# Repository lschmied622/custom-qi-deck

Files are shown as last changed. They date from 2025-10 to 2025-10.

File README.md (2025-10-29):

# README — Crazyflie „Custom-Qi-Deck“ (DE/EN)

> **Kurzbeschreibung.** Dieses Repository bündelt alle Artefakte der Bachelorarbeit zur Entwicklung eines *Custom-Qi-Decks* für die Crazyflie-Plattform, inklusive Elektronik (PCB), Mechanik (3D-Druck), Firmware und Skripten. Das Deck nutzt die **1-Wire-Deck-Identifikation** der Crazyflie 2.x, sodass beim Booten automatisch der passende Treiber geladen wird. Ohne beschriebene *Deck-EEPROM/One-Wire-Memory* stoppt die Drohne den Bootvorgang, bei nicht korrekt beschriebenem Speicher lädt die Drohne den Treiber nicht, weshalb die nachfolgenden Schritte zur EEPROM-Programmierung obligatorisch sind, um eine korrekte Funktionalität des Gesamtsystems zu gewährleisten. ([Bitcraze][1])

---

## 🇩🇪 Deutsch

### 1. Projektüberblick und Repository-Struktur

Die Ordnerstruktur ist bewusst so gewählt, dass Einsteigerinnen und Einsteiger schnell handlungsfähig werden:

```
bachelor-thesis/
├── README.md
├── LICENSE
├── docs/
│   ├── thesis/                # Thesis-Quellen (LaTeX/Word)
│   ├── figures/               # Abbildungen
│   └── presentations/         # Foliensätze
├── software/
│   ├── stm32-firmware/        # Crazyflie-STM32-Firmware
│   ├── nrf-firmware/          # NRF51-Firmware
│   ├── python-scripts/        # Tools, Analyse, Kontrolle
│   └── shared-libraries/      # Gemeinsame Bibliotheken
├── hardware/
│   ├── kicad-project/         # KiCad (.sch, .kicad_pcb, ...)
│   ├── fabrication-files/     # Gerber, BoM, Pick&Place
│   └── images/                # Fotos PCB/Bestückung
├── mechanics/
│   ├── cad-models/            # STEP/STL/Fusion
│   ├── animations/            # Render/Simulation
│   ├── images/                # Renders/Exploded Views
│   └── videos/                # Demo-/Montagevideos
└── experiments/
    ├── flight-tests/
    ├── sensor-logs/
    └── analysis/
```

---

### 2. Voraussetzungen (kurz)

* **Hardware:** Crazyflie 2.x + Radio (Crazyradio PA), Flow-Deck & Multi-ranger (optional, je nach Versuch), *Custom-Qi-Deck* (dieses Projekt).
* **Software:** Python 3.10+, `cflib` (Crazyflie Python Library), Crazyflie Client (optional für Konsole/Log-Ansicht).
* **Werkzeuge:** KiCad (für Anpassungen), gängige PCB-Bestückungsausrüstung.

---

### 3. PCB bestellen und bestücken

**3.1 Fertigungsdateien verwenden.** Im Ordner `hardware/fabrication-files/` liegen **Gerber-Daten**, **BoM** (Stückliste) und **Pick-and-Place**-Dateien. Diese sind bei üblichen PCB-Fertigern direkt hochladbar.

> *Hinweis:* Die Crazyflie-Decks werden über die 2×5-Stiftleisten und einen **1-Wire-Memory-Chip** identifiziert, der auf dem PCB bestückt sein muss (siehe Abschnitt 4). ([Bitcraze][1])

**3.2 BoM (Stückliste).** Die BoM enthält **alle** Bauteile zur vollständigen Bestückung, inkl. des 1-Wire-Memorys. Prüfen Sie vor Bestellung die Gehäuseformen und Lötpads.

**3.3 Kurze Montageanleitung.** (Angelehnt an die Thesis-Montagekapitel)

1. **Vorbereitung:** Leiterplatte reinigen; Bauteile gemäß BoM bereitstellen.
2. **Kleinteile (SMD) löten:** Zuerst passiv, dann ICs; besonders sauber: Qi-Empfänger, Gleichrichter/Power-Path, **1-Wire-Memory**.
3. **Verbinder setzen:** Headerleisten (2×10) exakt rechtwinklig.
4. **Mechanik prüfen:** Deckform und ggf. 3D-gedruckte Führung/„Ladetrichter“ aus `mechanics/cad-models/` kontrollieren und anpassen.
5. **Sichtprüfung & Reinigung:** Kurzschlussprüfung, Flussmittelreste entfernen.

> *Die Crazyflie liest am Start alle 1-Wire-Memories der Decks und initialisiert deren Treiber. Ein leeres/fehlerhaftes Deck-Memory kann das Starten verhindern oder die Funktionalität der anderen Decks, insbesondere dem Flowdeck, beeinflussen
> .* ([Bitcraze][1])

*Vorschau-Bilder:*

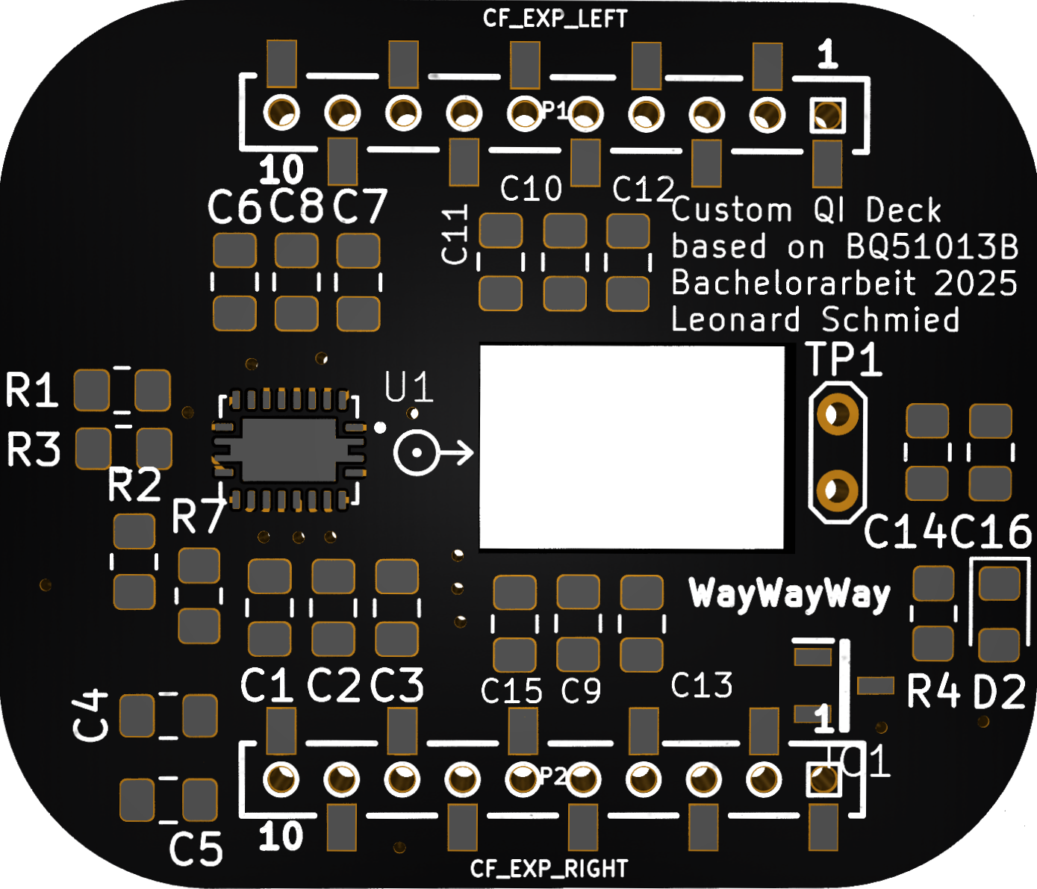
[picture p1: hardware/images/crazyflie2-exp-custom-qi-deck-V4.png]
Custom-Qi-Deck-frontsilk
 
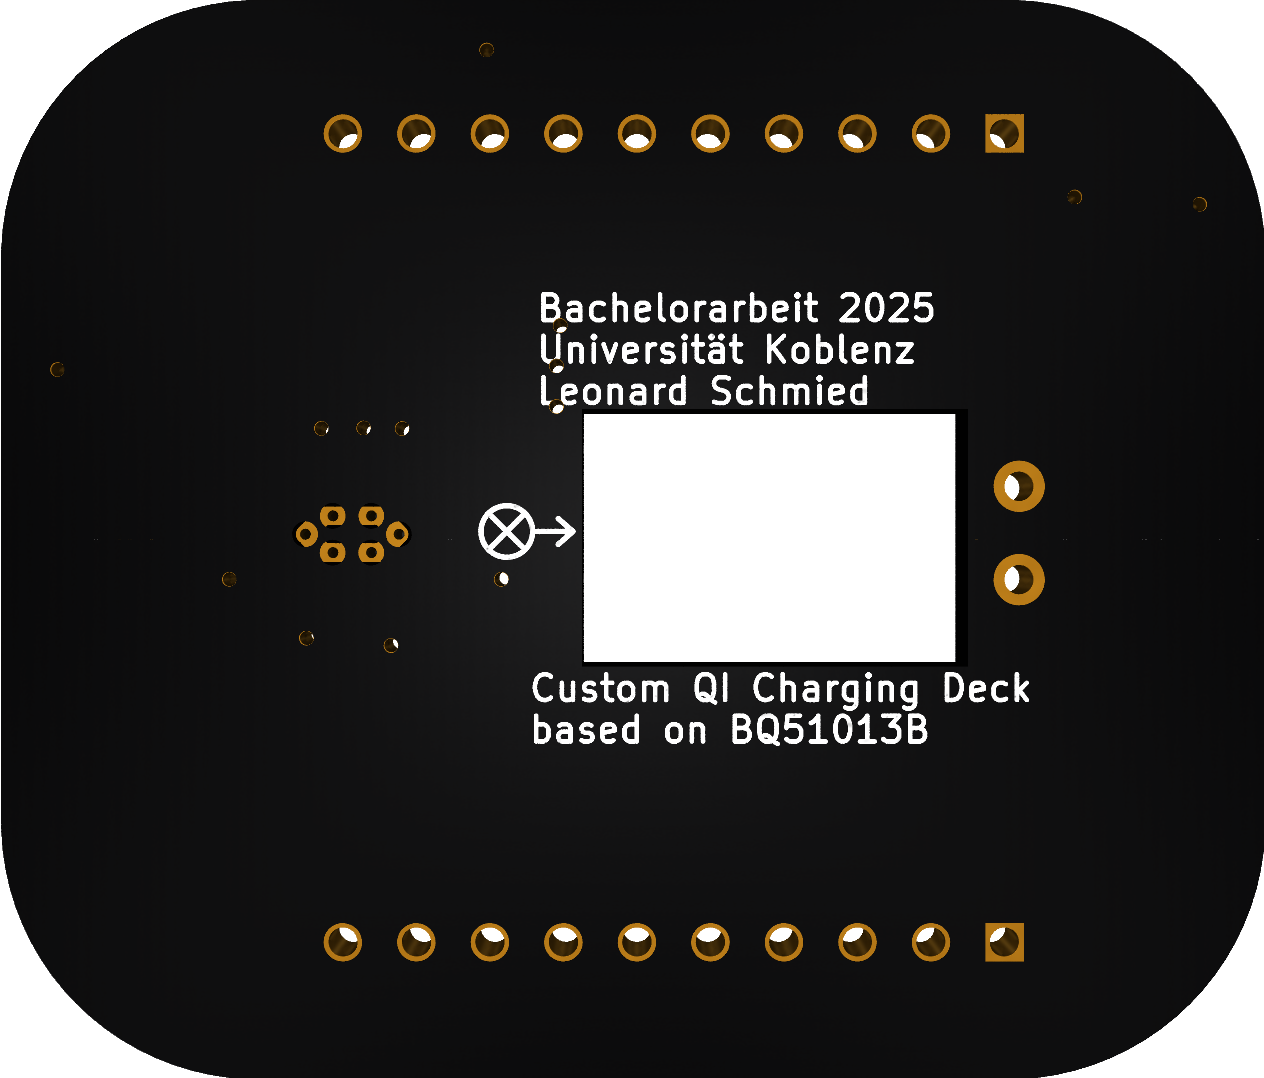
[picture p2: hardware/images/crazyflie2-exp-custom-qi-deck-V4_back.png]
Custom-Qi-Deck-backsilk


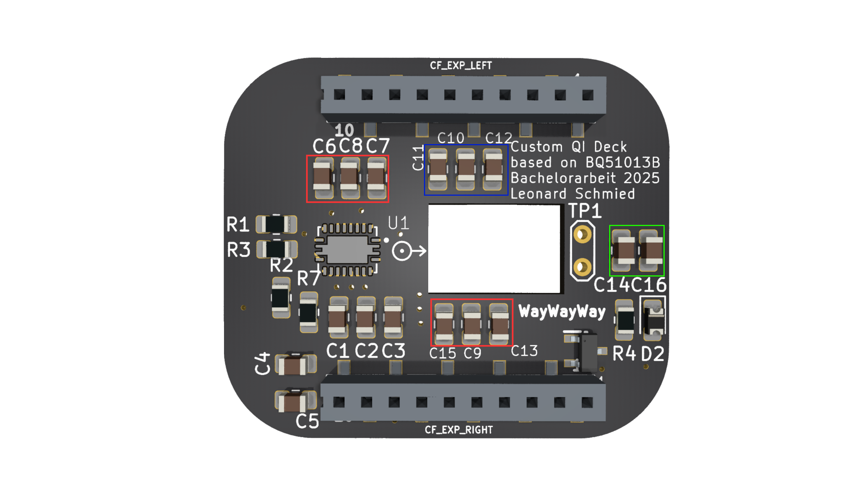
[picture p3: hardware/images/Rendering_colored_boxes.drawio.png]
Bestücktes PCB

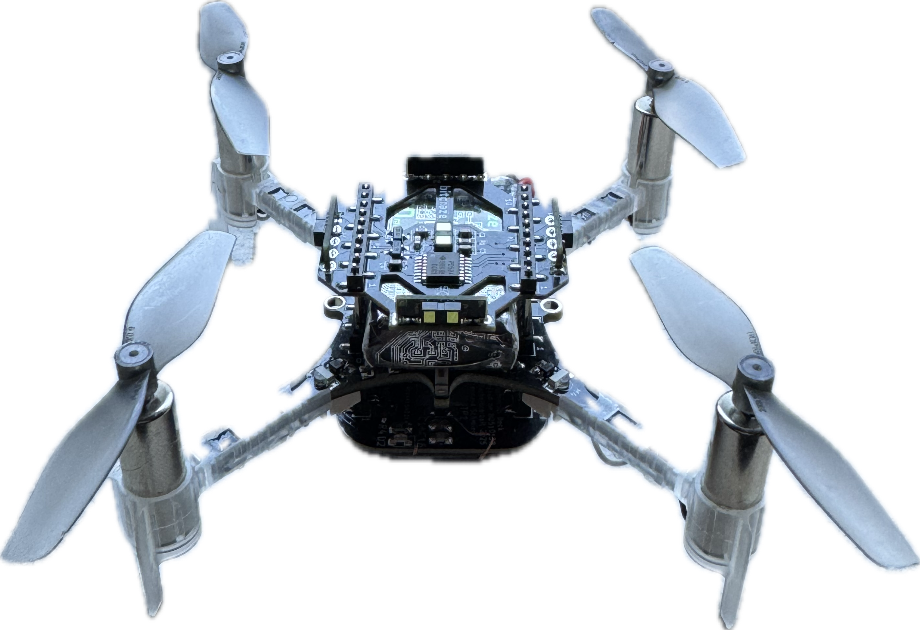
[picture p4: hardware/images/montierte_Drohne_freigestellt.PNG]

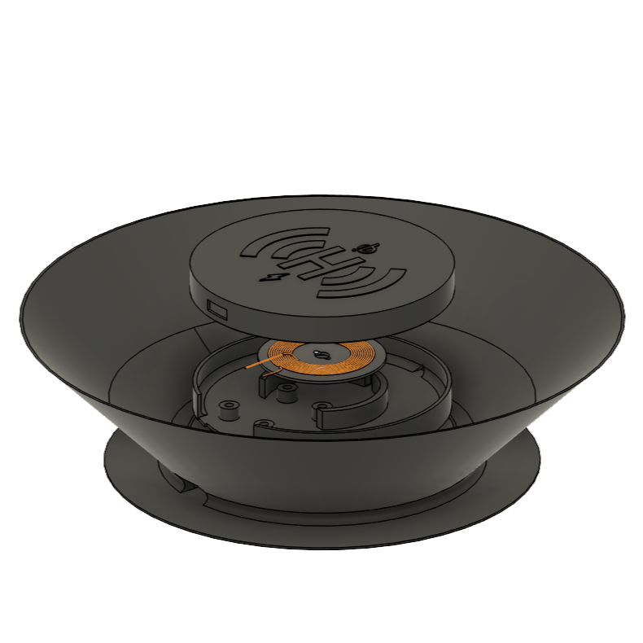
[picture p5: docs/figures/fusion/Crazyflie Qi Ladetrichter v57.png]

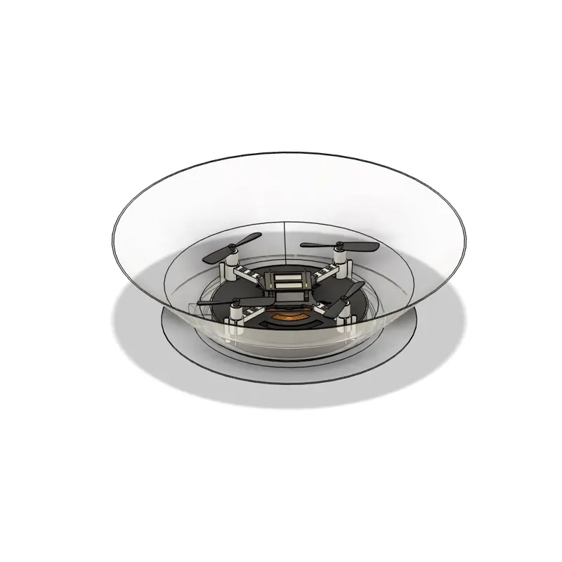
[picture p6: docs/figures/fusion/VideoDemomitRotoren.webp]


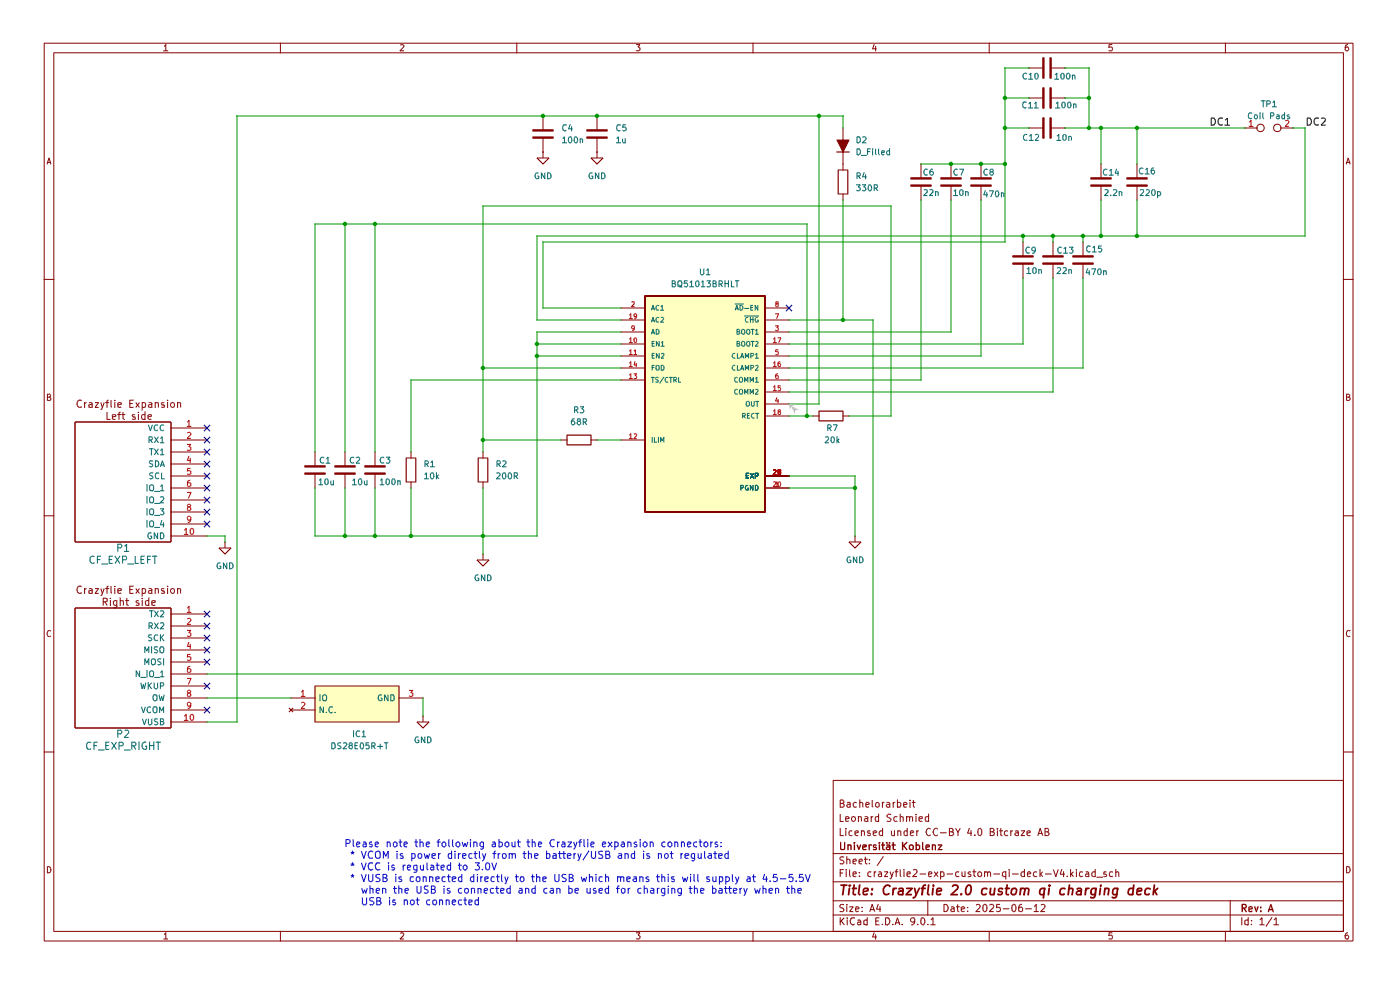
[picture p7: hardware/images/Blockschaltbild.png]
Qi-Schaltung (Prinzipskizze)


---

### 4. **Obligatorisch:** EEPROM/One-Wire-Memory programmieren

**Ziel.** Das Deck-EEPROM enthält Identitätsdaten (Vendor/Produkt/Name/Version), die der Crazyflie-Firmware erlauben, **Kompatibilität zu prüfen** und den **Treiber automatisch zu laden** (*Deck Enumeration*). ([Bitcraze][1])

**Werkzeuge.** Bitcraze stellt CRTP-basierte *Memory-Access*-Funktionen sowie Beispielskripte zum **Lesen/Schreiben des 1-Wire-Speichers** bereit (z. B. `read-ow.py`/`write-ow.py` in der Crazyflie-Python-Bibliothek). ([Bitcraze][2])

**Vorgehen (empfohlen):**

1. Crazyflie einschalten; per Radio verbinden.
2. Skript `write-ow.py` (oder eigenes Tool) verwenden, um das Deck-Memory zu beschreiben.
3. Reboot; Konsole prüfen (siehe **Validierung**).

**⚠️ WICHTIG:** Ohne korrekt geschriebenes EEPROM kann die Bootsequenz abbrechen bzw. der Treiber wird nicht geladen. ([Bitcraze][1])

**Platzhalter für Python-Code (anpassbar):**

```python
# replace method with this data:
    def _connected(self, link_uri):
        """ This callback is called form the Crazyflie API when a Crazyflie
        has been connected and the TOCs have been downloaded."""
        print('Connected to %s' % link_uri)

        mems = self._cf.mem.get_mems(MemoryElement.TYPE_1W)
        print('Found {} 1-wire memories'.format(len(mems)))
        if len(mems) > 0:
            print('Writing test configuration to'
                  ' memory {}'.format(mems[0].id))

            deck_name = 'custom_qi'

            # Setting VID:PID to 00:00 will make the Crazyflie match driver to the board name
            mems[0].vid = 0x00 #0xBC
            mems[0].pid = 0x00 #0x0F
            mems[0].pins = 0x0C #0x0C
            mems[0].name = deck_name
            mems[0].valid = True

            board_name_id = OWElement.element_mapping[1]
            board_rev_id = OWElement.element_mapping[2]

            mems[0].elements[board_name_id] = deck_name
            mems[0].elements[board_rev_id] = 'A'

            mems[0].write_data(self._data_written)
# TODO: Mit cflib examples/memory/write-ow.py an Deck schreiben.
```

> *Hinweis:* Details zum **Deck-Memory-Format** und zur **Memory-API** finden sich in der offiziellen Dokumentation. Stimmen Sie Felder und Prüfsummen mit dem verwendeten Tooling ab. ([Bitcraze][3])

---

### 5. Validierung (Konsole/Boot-Logs)

Nach dem Neustart sollte die Crazyflie in der **Konsole** (Crazyflie-Client) ausgeben, dass ein Deck-Memory gefunden wurde und der passende Treiber geladen ist. Suchen Sie nach Mustern wie:

```
...
DECK_CORE: 3 deck(s) found
DECK_CORE: Calling INIT on driver custom_qi for deck 0
[CUSTOM_QI] driver initialized
DECK_CORE: Calling INIT on driver bcMultiranger for deck 1
[CUSTOM_QI] task started
DECK_CORE: Calling INIT on driver bcFlow2 for deck 2
...
DECK_CORE: Deck 0 test [OK].
...
DECK_CORE: Deck 1 test [OK].
DECK_CORE: Deck 2 test [OK].
SYS: Self test passed!
STAB: Wait for sensor calibration...
SYS: Free heap: 12432 bytes
STAB: Starting stabilizer loop
```

> *Je nach Firmwareversion variieren die Strings leicht; entscheidend ist die Erkennung des Deck-Namens und das Laden des Treibers.* (Hintergrund: Deck-Enumeration via 1-Wire/MEM-Subsystem.) ([Bitcraze][1])

---

### 6. Sicherheitshinweis (USB)

> **Achtung – USB nicht verwenden!**
> Solange das **Custom-Qi-Deck aufgesteckt und aktiv verwendet** wird, **darf die USB-Schnittstelle der Crazyflie nicht genutzt** werden. Anderenfalls können **Fehlfunktionen** (u. a. in der Strompfad-Umschaltung) auftreten.

---

### 7. Wall-Follow-Demo

> **Hinweis:** Im Ordner `experiments/flight-tests/` finden Sie Aufzeichnungen zur Wall-Follow-Demo mit dem Custom-Qi-Deck. Diese Demo nutzt den Multi-Ranger-Sensor zur Abstandsmessung und zeigt die Flugstabilität mit dem neuen Deck.

Für die Wall-Follow-Demo wurde ein einfacher PID-Regler implementiert, der die seitlichen Abstände zum Hindernis misst und die Position der Crazyflie entsprechend anpasst. Anschließend landet die Drohne sicher auf der Qi-Ladestation in einer vordefinierten Position. Nach einer kurzen Ladephase hebt die Drohne wieder ab und fliegt weiter an der Wand entlang, indem sie zu dem Initialzustand der FSM zurückkehrt. Die folgende Abbildung zeigt den schematischen Ablauf der Wall-Follow-Demo:

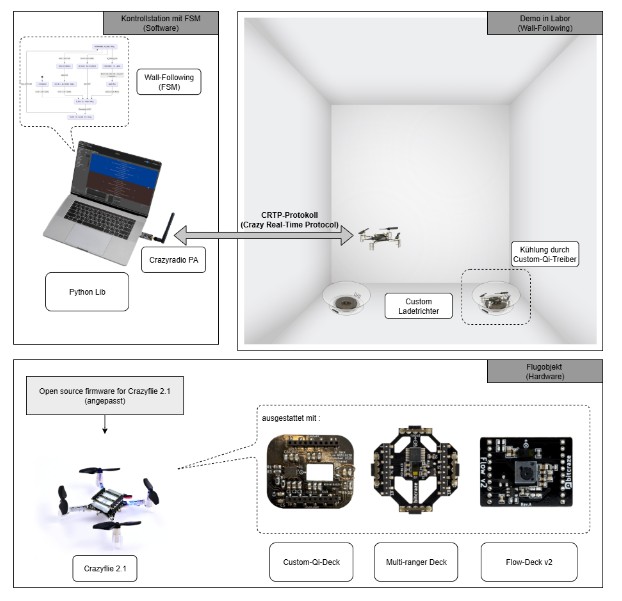
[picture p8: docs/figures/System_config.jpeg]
Wall-Follow-Demo FSM


### 8. Software/Firmware (kurz)

* **STM32/NRF-Firmware:** Quellen unter `software/stm32-firmware/` und `software/nrf-firmware/`.
  * Flashen der Crazyflie-Firmware (STM32, cf2.bin inkl. Custom-Qi-Treiber)
    * Manuell in den Bootloader wechseln (falls nötig). Crazyflie AUS → Power-Taste ~3 s drücken bis die blauen LEDs blinken → dann make cload ausführen.
    * Optional: Über den Crazyflie-Client die Firmware flashen (STM32 + NRF51).
    * In der NRF-Firmware kann optional die Fast-Charging-Funktionalität aktiviert werden, wenn der Treiber geladen ist und die Hardware durch den Prop-Wash kühlt.
* **Deck-Treiber:** Ein eigener Treiber wird beim Booten anhand des Deck-Memorys geladen (siehe Doku zur Deck-API/How-To für Deck-Treiber). ([Bitcraze][4])
* **Python-Skripte:** In `software/python-scripts/` liegen Hilfs- und Validierungs-Skripte (Logging, Wall-Following-Demos etc.).

---

### 9. 3D-Modelle und Mechanik

* **Trichter und Lad-Pad:** die 3D-Modelle für den Ladetrichter und das Qi-Ladepad befinden sich in `mechanics/cad-models/components` (STEP/STL/Fusion).
* **Makerworld:** Die Modelle sind auch auf [Makerworld](https://makerworld.io/) verfügbar: [Qi Charging Kit](https://makerworld.com/de/models/1899630-crazyflie-charging-funnel#profileId-2035758)
  * hier finden Sie auch Anleitungen, fertig sliced Modelle zum 3D-Druck und zur Montage.
* **Qi-Transmitter:** Für den Qi-Sender (Ladestation) wurde ein handelsübliches Modul verwendet (z. B. [Qi Wireless Charger](https://de.aliexpress.com/item/1005007750862678.html)).

---

### 10. Referenzen

* Bitcraze: **Expansion board detection** (1-Wire-Memory, Boot-Ablauf). ([Bitcraze][1])
* Bitcraze: **Deck memory format** (Aufbau/CRC, Zweck). ([Bitcraze][3])
* Bitcraze: **CRTP Memory access** (Lesen/Schreiben von 1-Wire-Memories). ([Bitcraze][2])
* Bitcraze Forum: **read-ow.py / write-ow.py** (Beispiele). ([forum.bitcraze.io][5])
* Bitcraze: **Expansion-Template (KiCad)** (Design-Startpunkt). ([GitHub][6])

---

## 🇬🇧 English

### 1. Project overview & repository layout

This repository bundles all artifacts of the bachelor thesis developing a *Custom-Qi-Deck* for the Crazyflie platform, including electronics (PCB), mechanics (3D printing), firmware and scripts. The deck uses the **1-Wire deck identification** of the Crazyflie 2.x so the appropriate driver is automatically loaded during boot. Without a programmed *deck EEPROM/one-wire memory* the drone may abort the boot process or the driver will not be loaded, therefore the following steps to program the EEPROM are mandatory to ensure correct system functionality. ([Bitcraze][1])

---

### 2. Prerequisites (quick)

* **Hardware:** Crazyflie 2.x + radio (Crazyradio PA), Flow-Deck & Multi-Ranger (optional, depending on experiment), *Custom-Qi-Deck* (this project).
* **Software:** Python 3.10+, `cflib` (Crazyflie Python Library), Crazyflie Client (optional for console/log view).
* **Tools:** KiCad (for modifications), common PCB assembly tooling.

---

### 3. PCB ordering and assembly

**3.1 Use the fabrication files.** The folder `hardware/fabrication-files/` contains **Gerber data**, the **BoM** (bill of materials) and **pick-and-place** files. These can be uploaded directly to typical PCB manufacturers.

> *Note:* Crazyflie expansion decks are identified via the 2×5 pin header and a **1-Wire memory chip** which must be populated on the PCB (see section 4). ([Bitcraze][1])

**3.2 BoM (bill of materials).** The BoM contains **all** components required for full assembly, including the 1-Wire memory. Verify package types and solder pads before ordering.

**3.3 Short assembly guide.** (Based on the thesis assembly chapters)

1. **Preparation:** Clean the PCB; stage components according to the BoM.
2. **SMD first:** solder passives first, then ICs; pay special attention to the Qi receiver, rectifier/power-path, and the **1-Wire memory**.
3. **Place headers:** Ensure the 2×10 pin headers are soldered exactly orthogonal.
4. **Mechanics check:** Verify the deck outline and the optionally 3D-printed guide/"charging funnel" from `mechanics/cad-models/` and adapt if needed.
5. **Inspection & cleaning:** Check for shorts, remove flux residues.

> *The Crazyflie reads all 1-Wire memories of connected decks at startup and initializes their drivers. An empty or invalid deck memory can prevent boot or affect other decks (notably the Flowdeck).* ([Bitcraze][1])

---

### 4. **Mandatory:** Program the deck EEPROM/1-Wire memory

**Goal.** The deck EEPROM contains identity data (vendor/product/name/version) that allows the Crazyflie firmware to **verify compatibility** and **auto-load the correct driver** (deck enumeration). ([Bitcraze][1])

**Tools.** Bitcraze provides CRTP-based memory-access functions and example scripts for **reading/writing the 1-Wire memory** (e.g. `read-ow.py` / `write-ow.py` in the Crazyflie Python library). ([Bitcraze][2])

**Recommended procedure:**

1. Power the Crazyflie and connect via radio.
2. Use the `write-ow.py` script (or your own tool) to write the deck memory.
3. Reboot and check the console (see **Validation**).

**⚠️ IMPORTANT:** Without a correctly written EEPROM the boot sequence can fail or the driver will not be loaded. ([Bitcraze][1])

**Placeholder Python snippet (customize IDs):**

```python
# replace method with this data:
    def _connected(self, link_uri):
        """ This callback is called form the Crazyflie API when a Crazyflie
        has been connected and the TOCs have been downloaded."""
        print('Connected to %s' % link_uri)

        mems = self._cf.mem.get_mems(MemoryElement.TYPE_1W)
        print('Found {} 1-wire memories'.format(len(mems)))
        if len(mems) > 0:
            print('Writing test configuration to'
                  ' memory {}'.format(mems[0].id))

            deck_name = 'custom_qi'

            # Setting VID:PID to 00:00 will make the Crazyflie match driver to the board name
            mems[0].vid = 0x00 #0xBC
            mems[0].pid = 0x00 #0x0F
            mems[0].pins = 0x0C #0x0C
            mems[0].name = deck_name
            mems[0].valid = True

            board_name_id = OWElement.element_mapping[1]
            board_rev_id = OWElement.element_mapping[2]

            mems[0].elements[board_name_id] = deck_name
            mems[0].elements[board_rev_id] = 'A'

            mems[0].write_data(self._data_written)
# TODO: write DECK_INFO to the deck 1-Wire memory using cflib or write-ow.py
```

> *Note:* For details about the deck memory format and the memory API consult the official documentation. Align fields and checksums with the tooling you use. ([Bitcraze][3])

---

### 5. Validation (console / boot logs)

After rebooting the Crazyflie, check the **console** in the Crazyflie client. You should see that a deck memory was found and the appropriate driver was loaded. Look for patterns such as:

```
...
DECK_CORE: 3 deck(s) found
DECK_CORE: Calling INIT on driver custom_qi for deck 0
[CUSTOM_QI] driver initialized
DECK_CORE: Calling INIT on driver bcMultiranger for deck 1
[CUSTOM_QI] task started
DECK_CORE: Calling INIT on driver bcFlow2 for deck 2
...
DECK_CORE: Deck 0 test [OK].
...
DECK_CORE: Deck 1 test [OK].
DECK_CORE: Deck 2 test [OK].
SYS: Self test passed!
STAB: Wait for sensor calibration...
SYS: Free heap: 12432 bytes
STAB: Starting stabilizer loop
```

> *Messages vary with firmware versions; the key is that the deck name is detected and the driver is initialized.* ([Bitcraze][1])

---

### 6. Safety notice (USB)

> **Warning – do not use USB!**
> While the **Custom-Qi-Deck is attached and actively used**, the Crazyflie's USB interface must not be used. Concurrent use can lead to **malfunctions** (e.g. in the power-path switching).

---

### 7. Wall-Follow demo

> *Note:* The folder `experiments/flight-tests/` contains recordings for the Wall-Follow demo using the Custom-Qi-Deck. This demo uses the Multi-Ranger sensor for distance measurements and demonstrates flight stability with the new deck.

For the Wall-Follow demo a simple PID controller was implemented that measures lateral distance to an obstacle and adjusts the Crazyflie's position accordingly. Afterwards the drone lands on the Qi charger at a predefined position. After a short charging phase the drone takes off again and resumes flight along the wall by returning to the initial state of the FSM. The figure below shows the schematic sequence of the Wall-Follow demo:

Wall-Follow-Demo FSM

---

### 8. Software / Firmware (short)

* **STM32/NRF firmware:** sources in `software/stm32-firmware/` and `software/nrf-firmware/`.
  * Flashing the Crazyflie firmware (STM32, cf2.bin incl. custom Qi driver)
  * Enter the bootloader manually (if needed). Crazyflie OFF → hold the power button for ~3 s until the blue LEDs blink → then run make cload.
  * Optional: Flash the firmware via the Crazyflie Client (STM32 + NRF51).
  * In the NRF firmware, the fast-charging functionality can optionally be enabled when the driver is loaded and the hardware is cooled by prop wash.
* **Deck driver:** A dedicated driver is loaded at boot based on the deck EEPROM (see the Deck API / driver how-to). ([Bitcraze][4])
* **Python scripts:** helper and validation scripts (logging, wall-follow demos etc.) in `software/python-scripts/`.

---

### 9. 3D models and mechanics

* **Funnel and charging pad:** the 3D models for the charging funnel and the Qi charging pad are located in `mechanics/cad-models/components` (STEP / STL / Fusion).
* **Makerworld:** The models are also available on Makerworld: [Qi Charging Kit](https://makerworld.com/de/models/1899630-crazyflie-charging-funnel#profileId-2035758)
  * there you can find build instructions, ready-sliced 3D-print files and assembly guides.
* **Qi transmitter:** A commercially available Qi transmitter module was used for the charging station (e.g. `Qi Wireless Charger` — https://de.aliexpress.com/item/1005007750862678.html).

---

### 10. References

* Bitcraze: **Expansion board detection** (1-Wire-Memory, boot sequence). ([Bitcraze][1])
* Bitcraze: **Deck memory format** (layout/CRC, purpose). ([Bitcraze][3])
* Bitcraze: **CRTP memory access** (read/write 1-Wire memories). ([Bitcraze][2])
* Bitcraze forum: **read-ow.py / write-ow.py** (examples). ([forum.bitcraze.io][5])
* Bitcraze: **Expansion template (KiCad)** (design starting point). ([GitHub][6])

---

### License

Siehe `LICENSE`. Bitte zitieren/attribuieren Sie die verwendeten Bitcraze-Ressourcen gemäß deren Lizenzen/Guidelines. Vorlage/Template-Elektronik siehe Bitcraze-Projekt. ([GitHub][6])

---

> **Hinweis zur Reproduzierbarkeit:** Für die elektrische Deck-Erkennung und das automatische Treiber-Laden sind das **1-Wire-Deck-Memory** und dessen **korrekter Inhalt** zentral. Prüfen Sie nach jeder Hardware-Änderung das Boot-Log. Die technische Funktionsweise ist in der offiziellen Dokumentation detailliert beschrieben. ([Bitcraze][1])

[1]: https://www.bitcraze.io/documentation/system/platform/cf2-expansiondecks/ "Expansion decks of the Crazyflie 2.x"
[2]: https://www.bitcraze.io/documentation/repository/crazyflie-firmware/master/functional-areas/crtp/crtp_mem/ "Memory access"
[3]: https://www.bitcraze.io/documentation/repository/crazyflie-firmware/master/functional-areas/deck_memory_format/ "Deck memory format"
[4]: https://www.bitcraze.io/documentation/repository/crazyflie-firmware/master/userguides/deck/ "Deck API"
[5]: https://forum.bitcraze.io/viewtopic.php?t=5105 "Where to see OW memory content?"
[6]: https://github.com/bitcraze/crazyflie2-exp-template-electronics "KiCad project for the Crazyflie 2.0 expansion template"

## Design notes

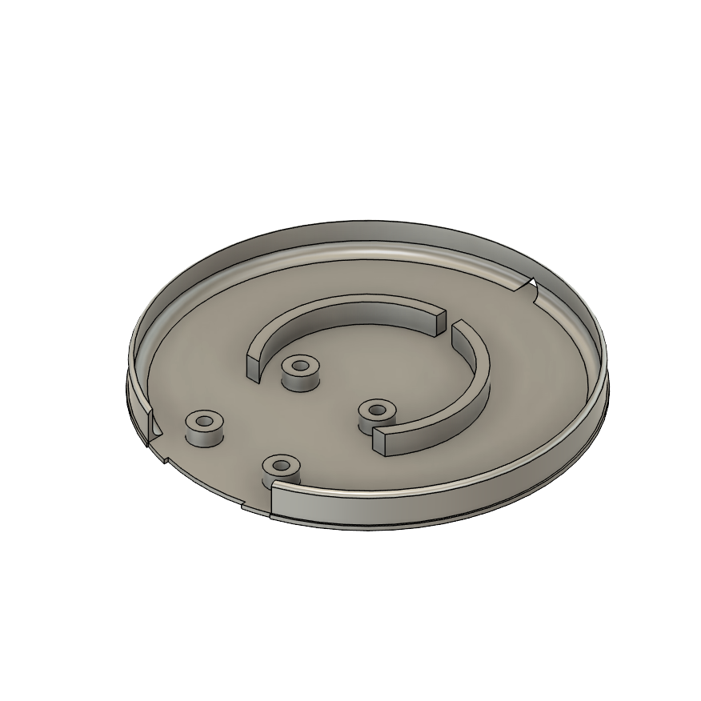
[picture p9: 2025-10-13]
mechanics/images/Boden.png

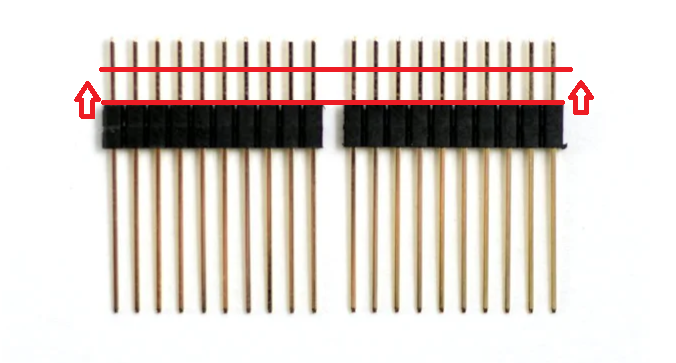
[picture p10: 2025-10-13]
docs/figures/05_hardware_entwurf/long-pin-headers-top.png

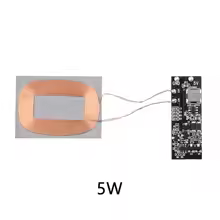
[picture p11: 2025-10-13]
docs/figures/05_hardware_entwurf/Qi-Receiver_Pre-Prototyp.png

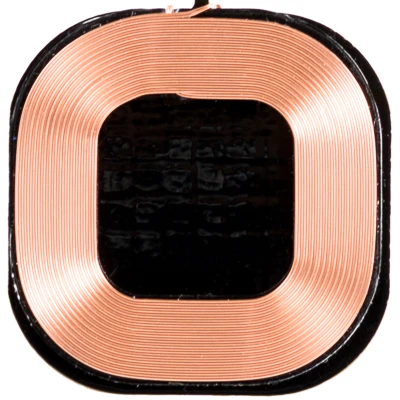
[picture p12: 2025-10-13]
docs/figures/05_hardware_entwurf/qi-charger-deck-1.2-400px-1_grande.png

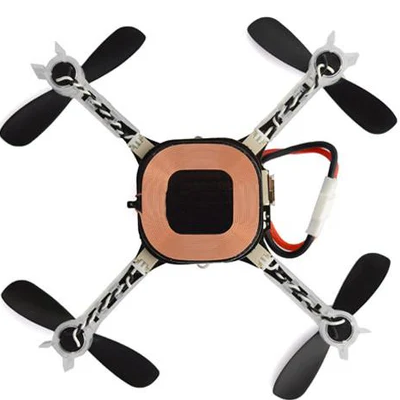
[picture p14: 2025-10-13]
docs/figures/05_hardware_entwurf/qi-deck-on-crazyflie_grande.png

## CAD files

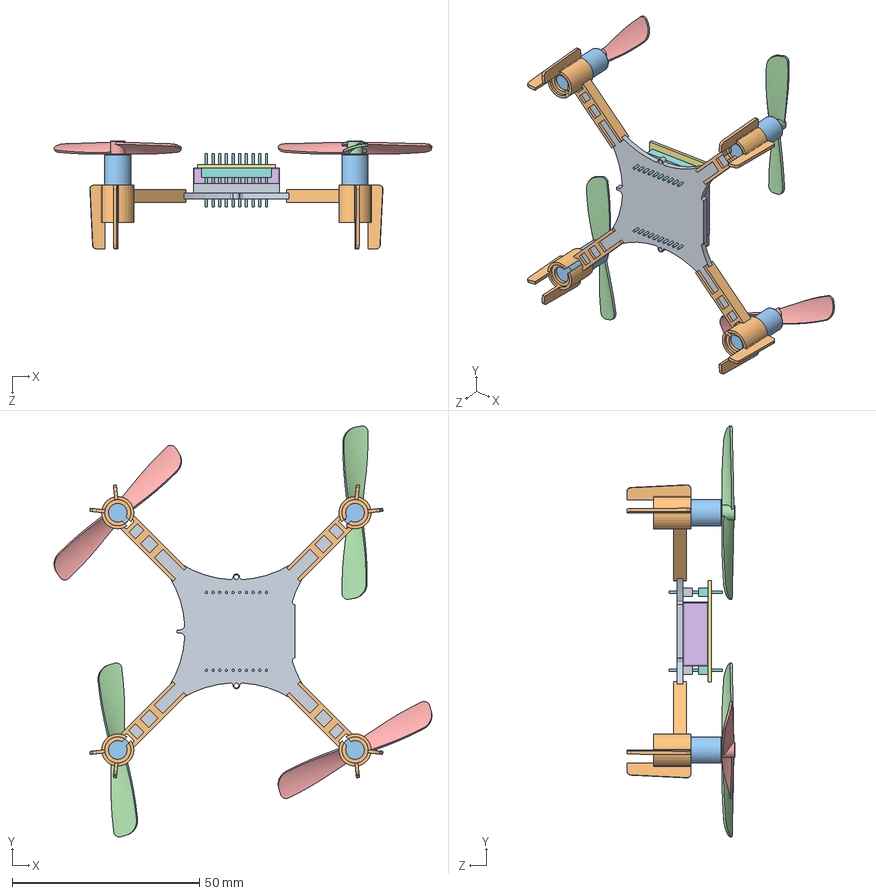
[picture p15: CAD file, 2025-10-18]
mechanics/cad-models/Crazyflie-CAD-master by rshum19/Crazyflie-CAD-master/Crazyflie_assembly.SLDASM
100.8 x 109.6 x 28.8 mm
pcb
7mm motor mount x 4
7x15 motor x 4
propeller_ccw x 2
propeller_cw x 2
battery bc-bl-01-a
battery holder board
header x 2

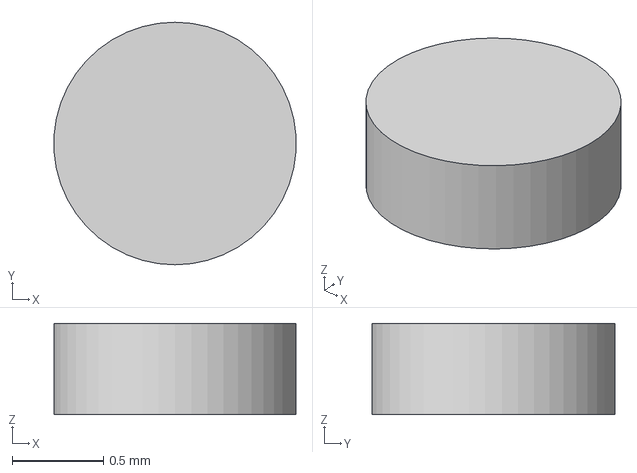
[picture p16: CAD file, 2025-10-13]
mechanics/cad-models/components/Deckel.3mf
1.33 x 1.33 x 0.5 mm

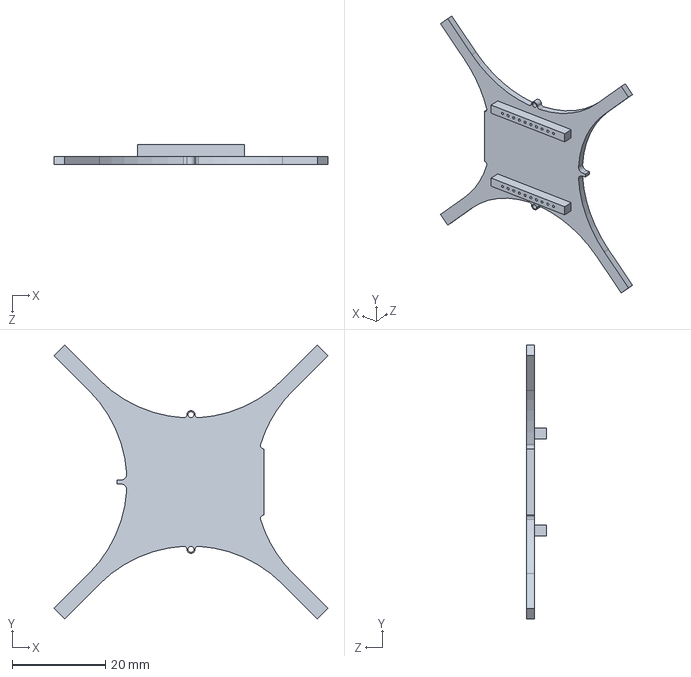
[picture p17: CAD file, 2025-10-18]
mechanics/cad-models/Crazyflie-CAD-master by rshum19/Crazyflie-CAD-master/pcb.SLDPRT
58.8 x 58.8 x 4.25 mm

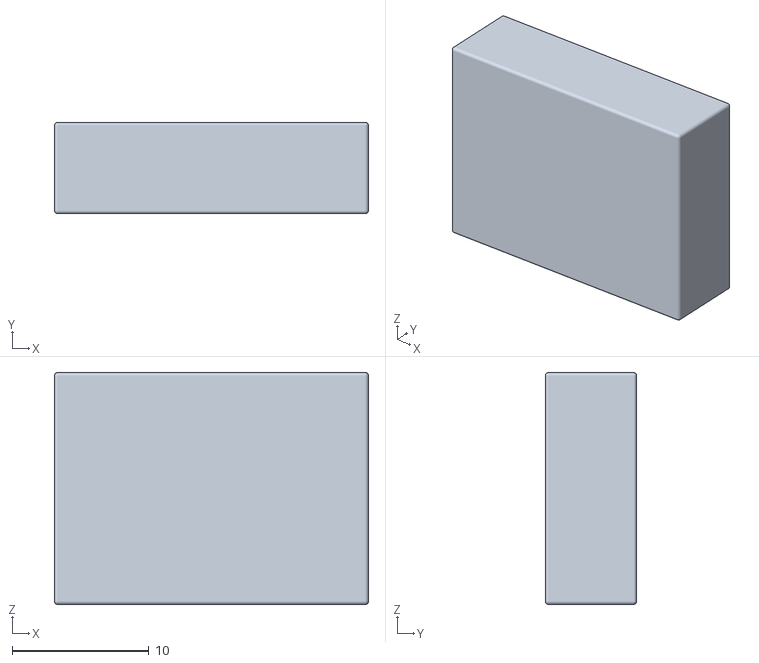
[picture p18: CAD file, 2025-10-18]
mechanics/cad-models/Crazyflie-CAD-master by rshum19/Crazyflie-CAD-master/STL/battery bc-bl-01-a_Default_sldprt.STL
23.0 x 6.70 x 17.0

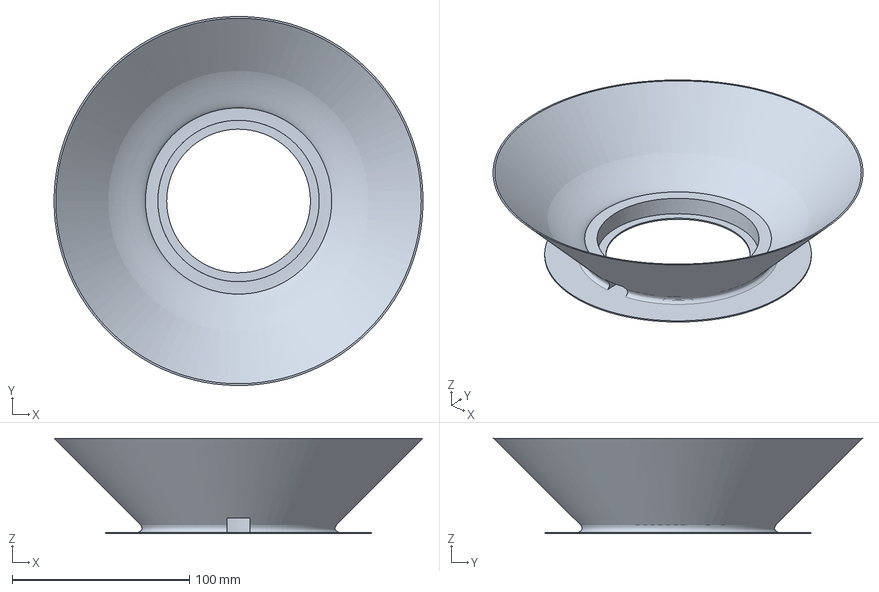
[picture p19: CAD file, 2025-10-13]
mechanics/cad-models/components/TrichterV2.3mf
208.0 x 208.0 x 53.8 mm

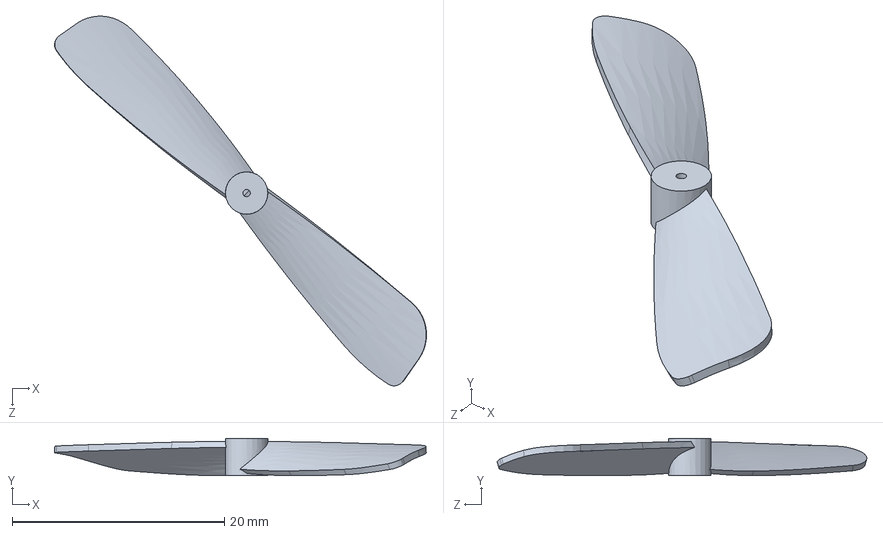
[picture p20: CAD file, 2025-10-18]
mechanics/cad-models/Crazyflie-CAD-master by rshum19/Crazyflie-CAD-master/propeller.SLDPRT
35.1 x 3.53 x 34.9 mm

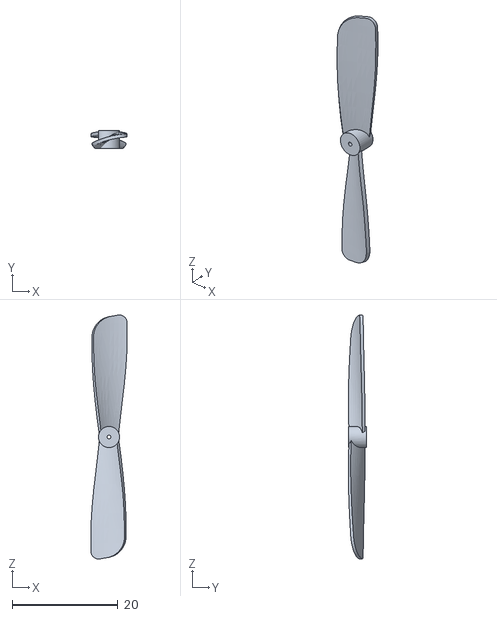
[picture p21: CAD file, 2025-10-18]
mechanics/cad-models/Crazyflie-CAD-master by rshum19/Crazyflie-CAD-master/STL/propeller_ccw_Default_sldprt.STL
6.91 x 3.50 x 46.3

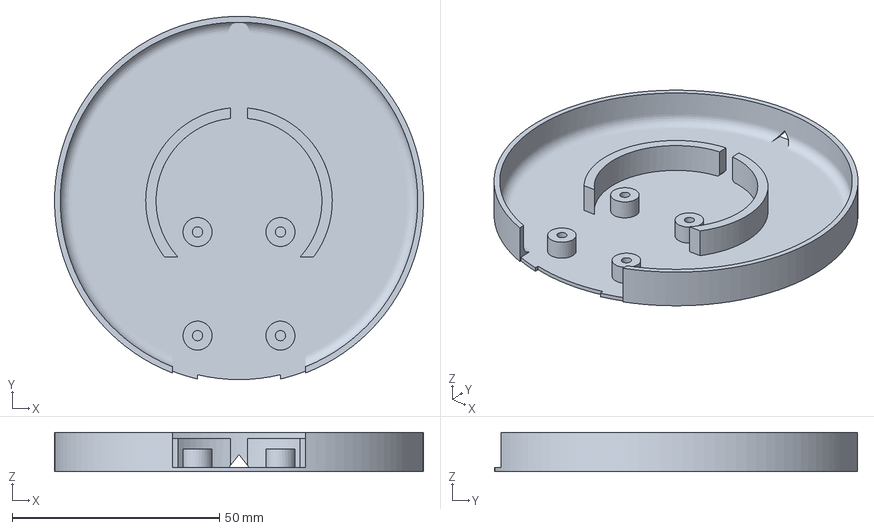
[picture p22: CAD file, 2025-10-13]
mechanics/cad-models/components/Boden.3mf
89.0 x 87.6 x 9.50 mm

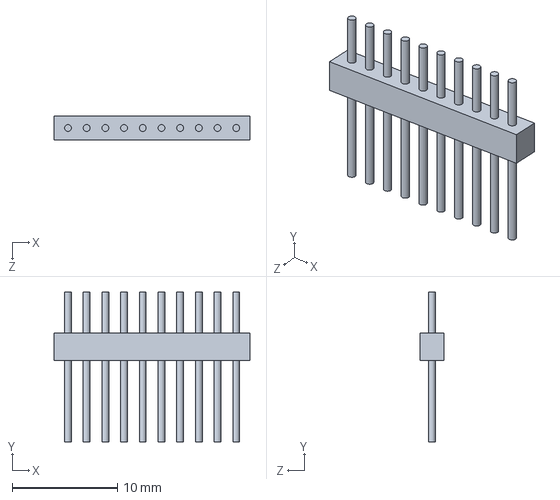
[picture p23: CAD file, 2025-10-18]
mechanics/cad-models/Crazyflie-CAD-master by rshum19/Crazyflie-CAD-master/header.SLDPRT
18.7 x 14.3 x 2.31 mm

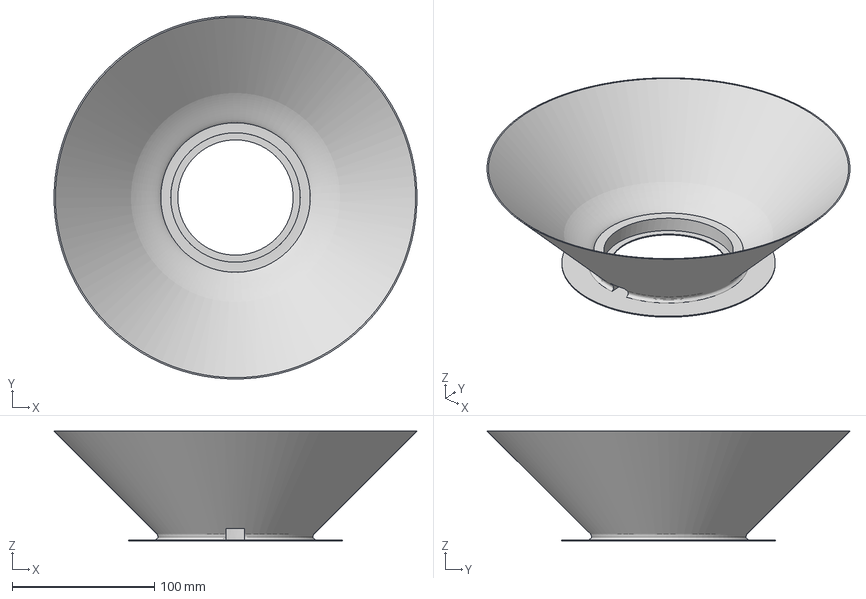
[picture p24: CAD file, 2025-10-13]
mechanics/cad-models/components/TrichterV2_long.3mf
255.0 x 255.0 x 77.2 mm

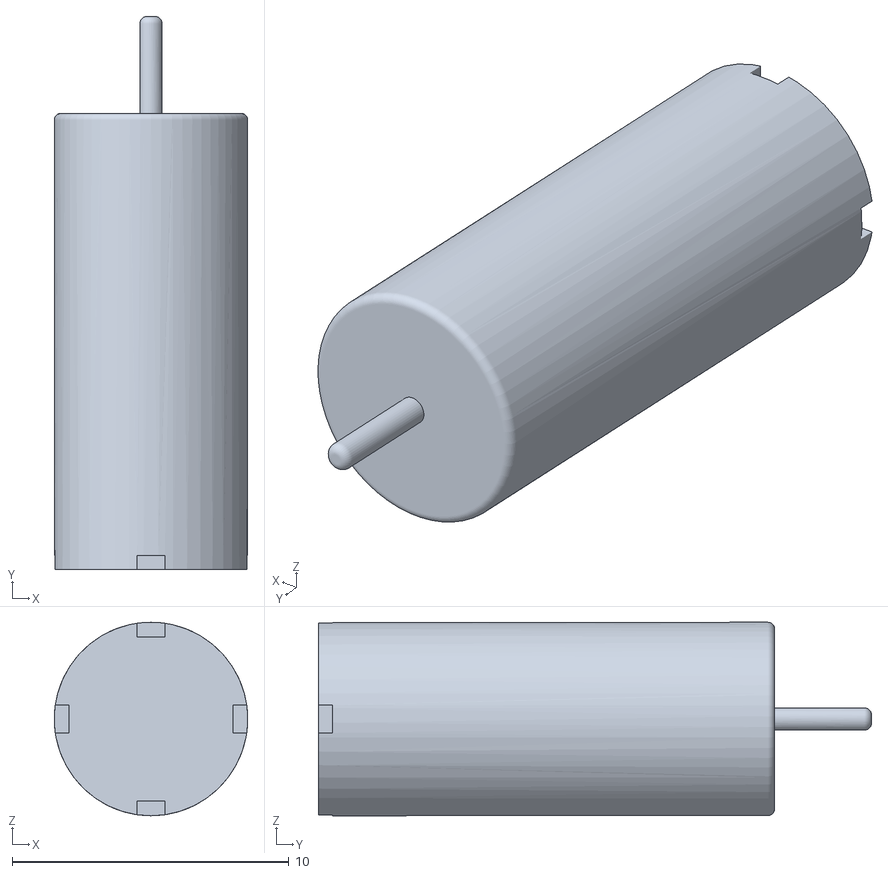
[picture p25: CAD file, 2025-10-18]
mechanics/cad-models/Crazyflie-CAD-master by rshum19/Crazyflie-CAD-master/STL/7x15 motor_Default_sldprt.STL
7.00 x 20.0 x 7.00

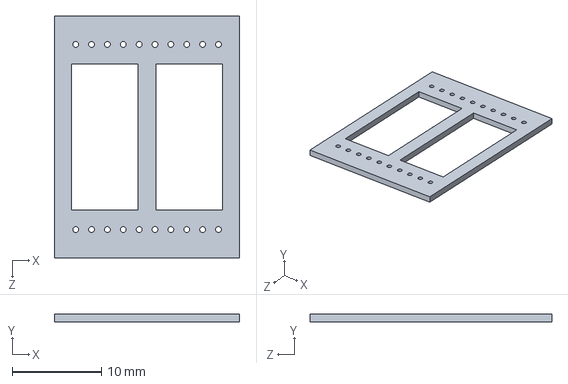
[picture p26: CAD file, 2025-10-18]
mechanics/cad-models/Crazyflie-CAD-master by rshum19/Crazyflie-CAD-master/battery holder board.SLDPRT
20.8 x 0.85 x 27.1 mm

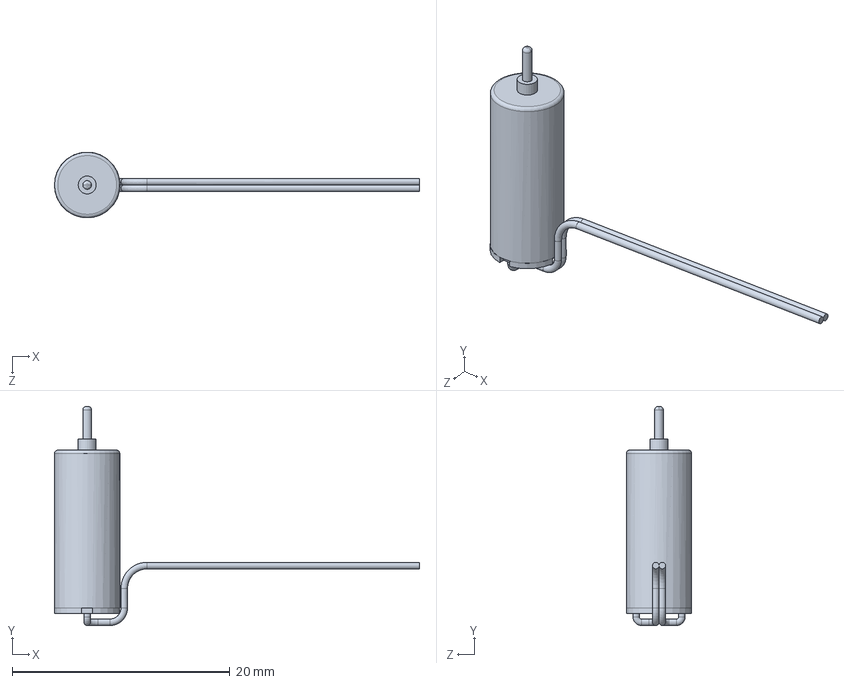
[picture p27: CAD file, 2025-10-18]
mechanics/cad-models/Crazyflie-CAD-master by rshum19/Crazyflie-CAD-master/6x15 motor mockup.SLDPRT
33.5 x 20.1 x 6.00 mm

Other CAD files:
mechanics/cad-models/Crazyflie-CAD-master by rshum19/Crazyflie-CAD-master/STL/propeller_cw_Default_sldprt.STL
mechanics/cad-models/Crazyflie-CAD-master by rshum19/Crazyflie-CAD-master/propeller_cw.SLDPRT
mechanics/cad-models/Crazyflie-CAD-master by rshum19/Crazyflie-CAD-master/STL/header_Default_sldprt.STL
mechanics/cad-models/Crazyflie-CAD-master by rshum19/Crazyflie-CAD-master/STL/pcb_Default_sldprt.STL
mechanics/cad-models/Crazyflie-CAD-master by rshum19/Crazyflie-CAD-master/STL/battery holder board_Default_sldprt.STL
mechanics/cad-models/Crazyflie-CAD-master by rshum19/Crazyflie-CAD-master/7mm motor mount.SLDPRT
mechanics/cad-models/Crazyflie-CAD-master by rshum19/Crazyflie-CAD-master/7x15 motor.SLDPRT
mechanics/cad-models/Crazyflie-CAD-master by rshum19/Crazyflie-CAD-master/CF_frame_marker_mount.SLDPRT
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

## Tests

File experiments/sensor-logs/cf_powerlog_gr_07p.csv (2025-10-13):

t_host_s | baro.temp_C | pm.batteryLevel_pct | pm.chargeCurrent_mA | pm.state | pm.vbat_V
0.212 | 32.111 | 10.000 | 0.001 | 0 | 3.294
0.412 | 32.123 | 10.000 | 0.001 | 0 | 3.283
0.610 | 32.132 | 10.000 | 0.001 | 0 | 3.283
0.810 | 32.140 | 10.000 | 0.001 | 0 | 3.283
1.010 | 32.140 | 10.000 | 0.001 | 0 | 3.283
1.211 | 32.135 | 10.000 | 0.001 | 0 | 3.283
1.410 | 32.130 | 10.000 | 0.001 | 0 | 3.278
1.611 | 32.130 | 10.000 | 0.001 | 0 | 3.283
1.810 | 32.138 | 10.000 | 0.001 | 0 | 3.278
2.010 | 32.161 | 10.000 | 0.001 | 0 | 3.278
2.209 | 32.184 | 10.000 | 0.001 | 0 | 3.278
2.409 | 32.195 | 10.000 | 0.001 | 0 | 3.278
2.609 | 32.204 | 10.000 | 0.001 | 0 | 3.278
2.808 | 32.220 | 10.000 | 0.001 | 0 | 3.273
3.008 | 32.242 | 10.000 | 0.001 | 0 | 3.273
3.208 | 32.256 | 10.000 | 0.001 | 0 | 3.273
3.408 | 32.268 | 10.000 | 0.001 | 0 | 3.273
3.608 | 32.278 | 10.000 | 0.001 | 0 | 3.273
3.808 | 32.280 | 10.000 | 0.001 | 0 | 3.273
4.008 | 32.270 | 10.000 | 0.001 | 0 | 3.273
4.207 | 32.285 | 10.000 | 0.001 | 0 | 3.273
4.407 | 32.305 | 10.000 | 0.001 | 0 | 3.267
4.608 | 32.317 | 10.000 | 0.001 | 0 | 3.267
4.808 | 32.319 | 10.000 | 0.001 | 0 | 3.267
5.008 | 32.329 | 10.000 | 0.001 | 0 | 3.267
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

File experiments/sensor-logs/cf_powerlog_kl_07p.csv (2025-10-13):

t_host_s | baro.temp_C | pm.batteryLevel_pct | pm.chargeCurrent_mA | pm.state | pm.vbat_V
0.208 | 31.264 | 10.000 | 0.725 | 1 | 3.690
0.407 | 31.274 | 10.000 | 0.787 | 1 | 3.690
0.609 | 31.287 | 10.000 | 0.794 | 1 | 3.674
0.807 | 31.303 | 10.000 | 0.745 | 1 | 3.674
1.007 | 31.310 | 10.000 | 0.750 | 1 | 3.674
1.208 | 31.310 | 10.000 | 0.760 | 1 | 3.674
1.407 | 31.314 | 10.000 | 0.787 | 1 | 3.674
1.607 | 31.325 | 10.000 | 0.763 | 1 | 3.679
1.806 | 31.331 | 10.000 | 0.766 | 1 | 3.674
2.006 | 31.334 | 10.000 | 0.756 | 1 | 3.679
2.206 | 31.348 | 10.000 | 0.764 | 1 | 3.679
2.405 | 31.375 | 10.000 | 0.762 | 1 | 3.679
2.606 | 31.383 | 10.000 | 0.769 | 1 | 3.679
2.806 | 31.389 | 10.000 | 0.780 | 1 | 3.679
3.006 | 31.400 | 10.000 | 0.749 | 1 | 3.679
3.206 | 31.422 | 10.000 | 0.712 | 1 | 3.679
3.405 | 31.450 | 10.000 | 0.762 | 1 | 3.684
3.607 | 31.473 | 10.000 | 0.754 | 1 | 3.684
3.805 | 31.489 | 10.000 | 0.764 | 1 | 3.684
4.005 | 31.513 | 10.000 | 0.763 | 1 | 3.684
4.208 | 31.525 | 10.000 | 0.781 | 1 | 3.684
4.405 | 31.541 | 10.000 | 0.711 | 1 | 3.684
4.605 | 31.554 | 10.000 | 0.783 | 1 | 3.690
4.804 | 31.570 | 10.000 | 0.783 | 1 | 3.690
5.004 | 31.589 | 10.000 | 0.739 | 1 | 3.690
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

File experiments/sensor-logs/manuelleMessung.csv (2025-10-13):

time_s | x_mm | y_mm | temperature_c
10 | 0.00 | 0.00 | 25.00
10 | 0.00 | 5.00 | 25.00
10 | 0.00 | 10.00 | 25.00
10 | 0.00 | 15.00 | 25.00
10 | 0.00 | 20.00 | 25.00
10 | 0.00 | 25.00 | 25.00
10 | 0.00 | 30.00 | 25.00
10 | 5.00 | 0.00 | 52.51
10 | 5.00 | 5.00 | 29.48
10 | 5.00 | 10.00 | 40.76
10 | 5.00 | 15.00 | 39.00
10 | 5.00 | 20.00 | 27.00
10 | 5.00 | 25.00 | 24.00
10 | 5.00 | 30.00 | 24.00
10 | 10.00 | 0.00 | 25.00
10 | 10.00 | 5.00 | 45.00
10 | 10.00 | 10.00 | 48.00
10 | 10.00 | 15.00 | 49.00
10 | 10.00 | 20.00 | 52.00
10 | 10.00 | 25.00 | 35.00
10 | 10.00 | 30.00 | 25.00
10 | 15.00 | 0.00 | 25.00
10 | 15.00 | 5.00 | 27.00
10 | 15.00 | 10.00 | 35.00
10 | 15.00 | 15.00 | 35.00
10 | 15.00 | 20.00 | 56.00
10 | 15.00 | 25.00 | 28.00
10 | 15.00 | 30.00 | 25.00
10 | 20.00 | 0.00 | 25.00
10 | 20.00 | 5.00 | 28.00
10 | 20.00 | 10.00 | 71.00
10 | 20.00 | 15.00 | 25.00
10 | 20.00 | 20.00 | 62.00
10 | 20.00 | 25.00 | 32.00
10 | 20.00 | 30.00 | 25.00
10 | 25.00 | 0.00 | 25.00
10 | 25.00 | 5.00 | 55.00
10 | 25.00 | 10.00 | 41.65
10 | 25.00 | 15.00 | 25.00
10 | 25.00 | 20.00 | 49.00
10 | 25.00 | 25.00 | 27.00
10 | 25.00 | 30.00 | 25.00
10 | 30.00 | 0.00 | 25.00
10 | 30.00 | 5.00 | 28.00
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

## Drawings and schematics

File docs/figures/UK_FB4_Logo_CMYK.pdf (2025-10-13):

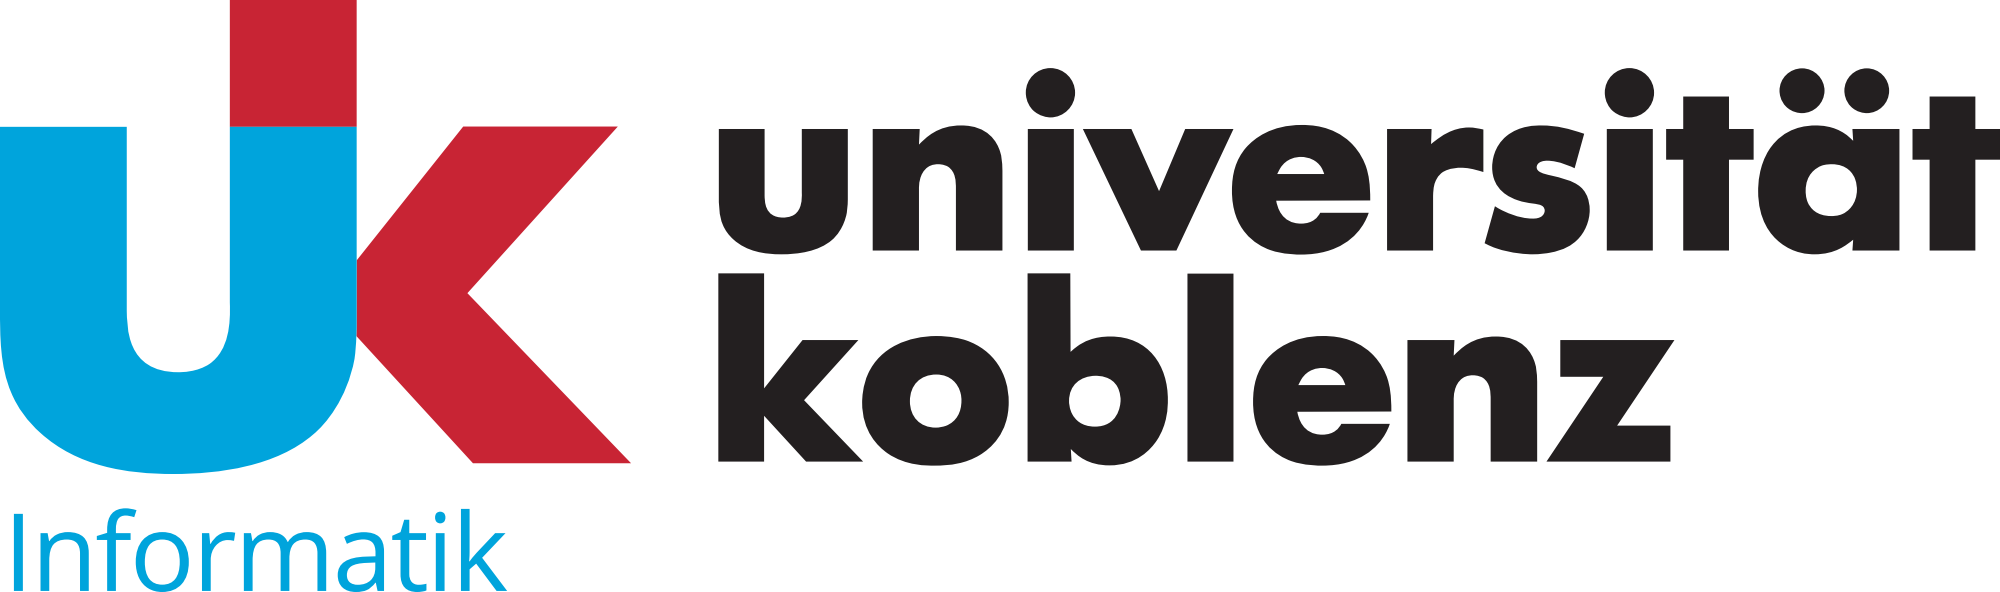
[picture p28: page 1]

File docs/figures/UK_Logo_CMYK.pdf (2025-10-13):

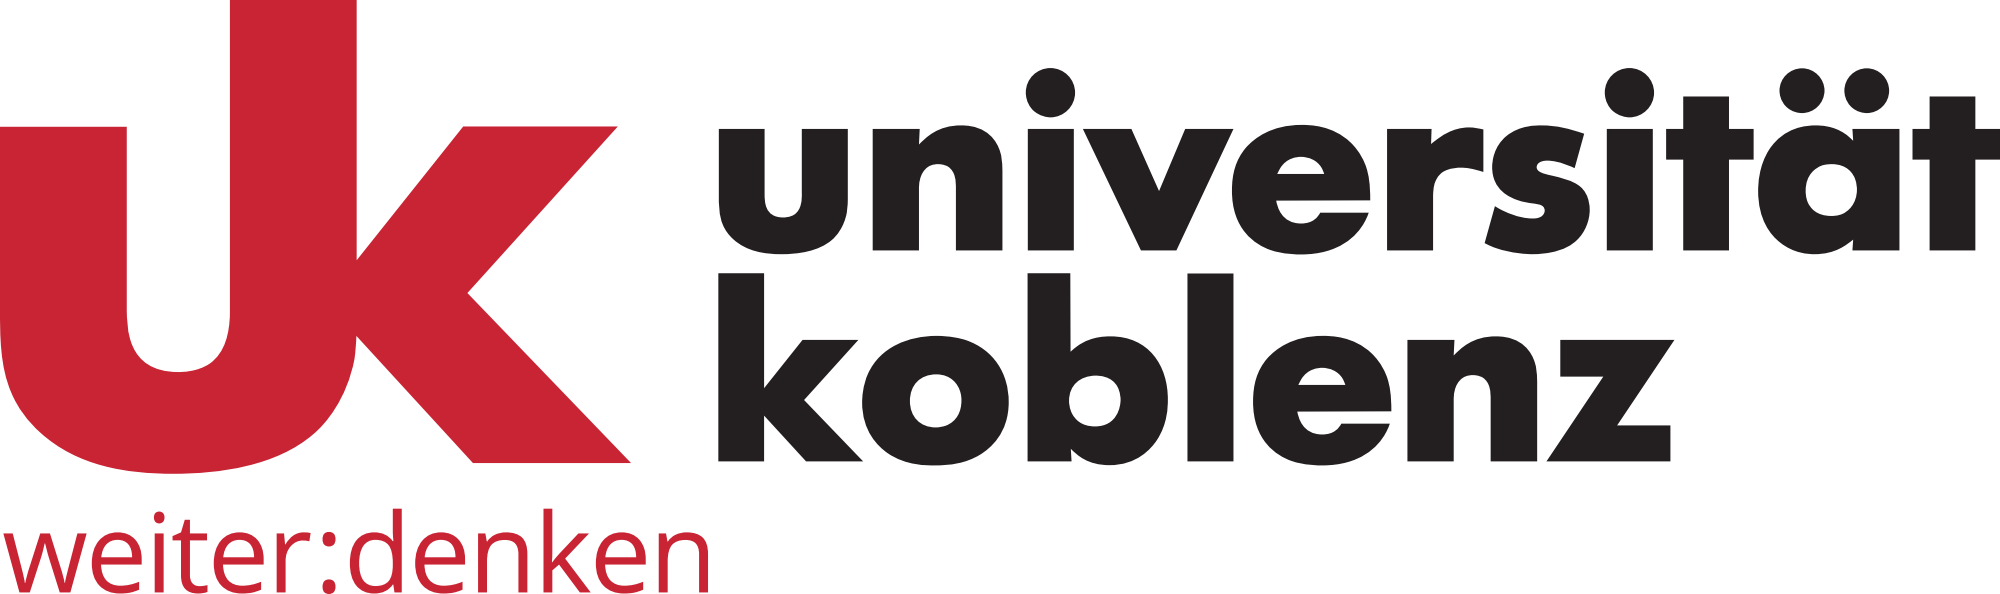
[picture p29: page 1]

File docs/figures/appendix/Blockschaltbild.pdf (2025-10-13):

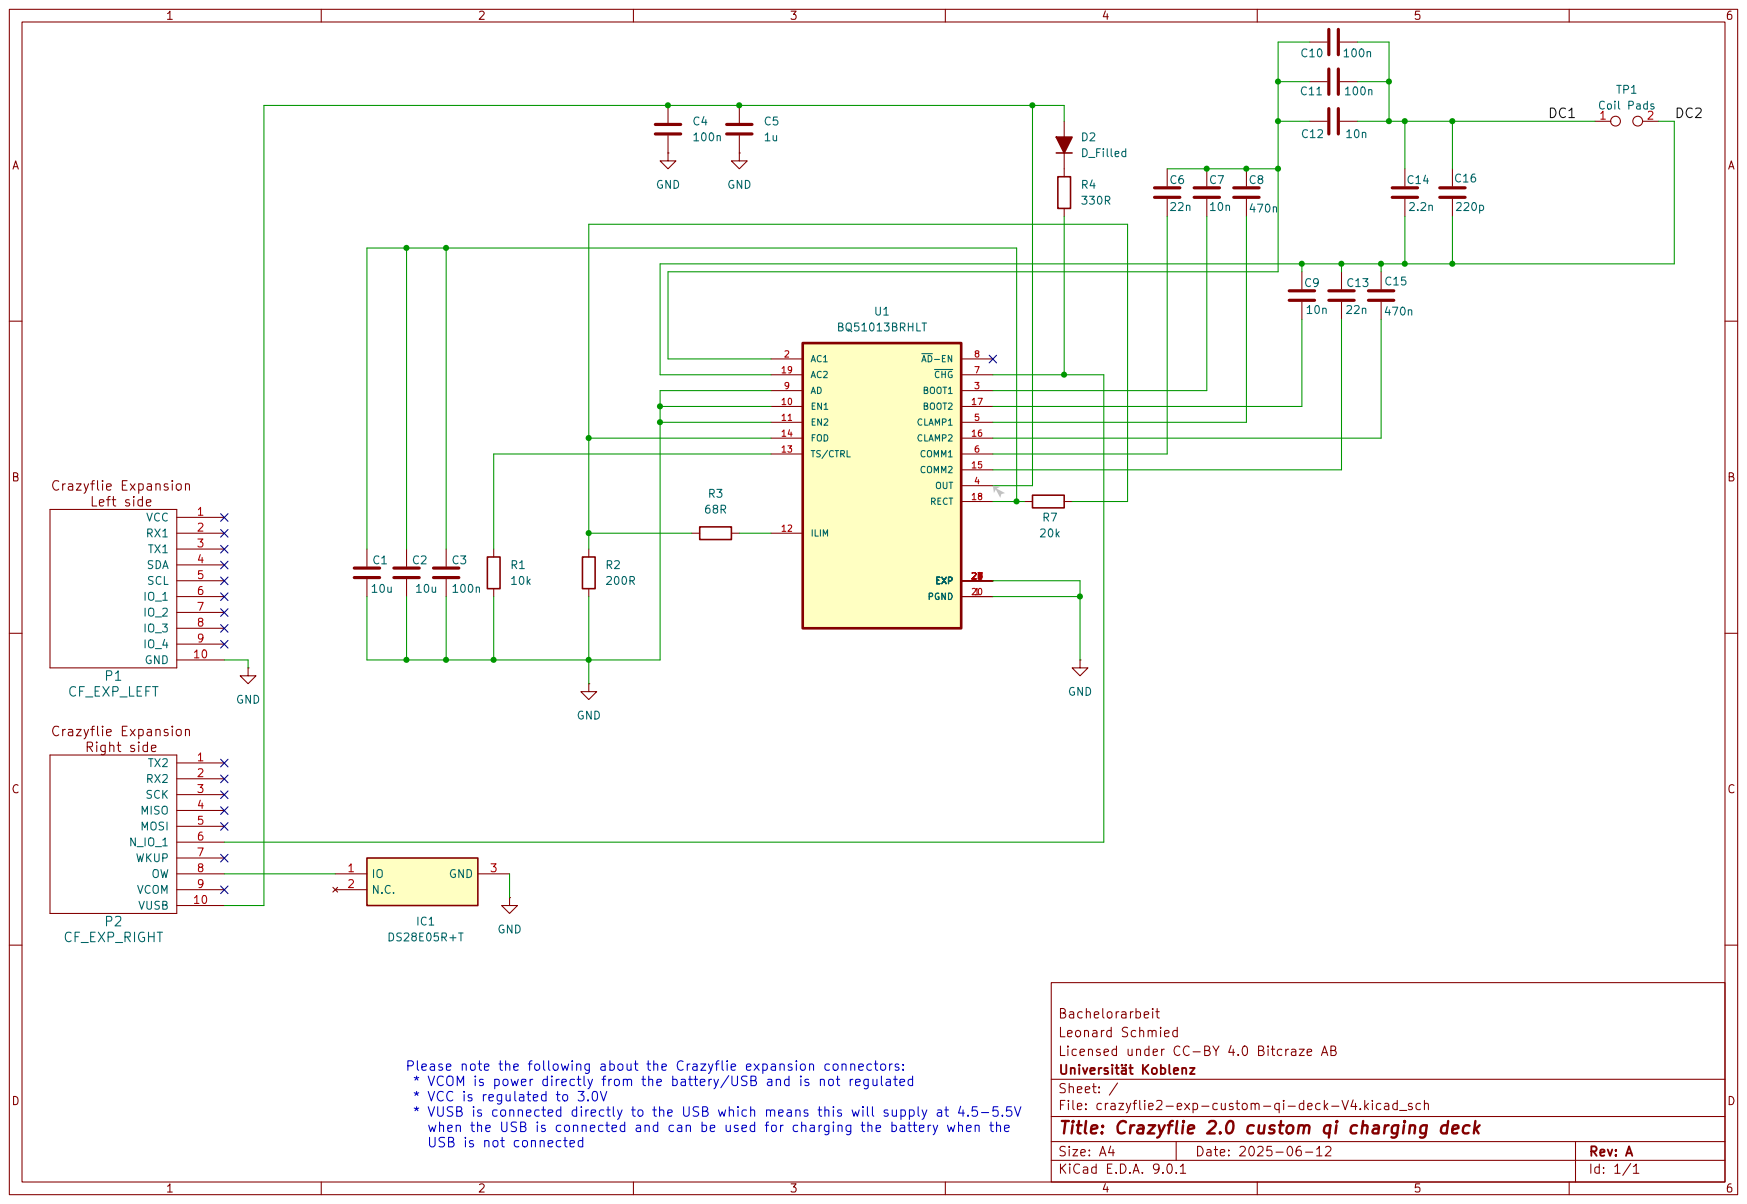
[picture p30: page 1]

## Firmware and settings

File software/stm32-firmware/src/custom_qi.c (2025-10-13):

#include <stdbool.h>
#include <stdint.h>
#include "deck.h"
#include "param.h"
#include "log.h"
#include "debug.h"
#include "motors.h"
#include "FreeRTOS.h"
#include "task.h"
#ifdef PM_H_EXISTS
#include "pm.h"
#endif

#define DEBUG_MODULE "CUSTOM_QI"

// ---------- API-Kompatibilität für ID-Validierung ----------
#ifndef LOG_ID_VALID
#  ifdef LOG_VARID_IS_VALID
#    define LOG_ID_VALID(id)        (LOG_VARID_IS_VALID(id))
#  else
#    ifdef LOG_VAR_ID_INVALID
#      define LOG_ID_VALID(id)      ((id) != LOG_VAR_ID_INVALID)
#    elif defined(LOG_VAR_ID_UNDEFINED)
#      define LOG_ID_VALID(id)      ((id) != LOG_VAR_ID_UNDEFINED)
#    else
#      define LOG_ID_VALID(id)      ((id) != (logVarId_t)-1)
#    endif
#  endif
#endif
#ifndef PARAM_ID_VALID
#  ifdef PARAM_VARID_IS_VALID
#    define PARAM_ID_VALID(id)      (PARAM_VARID_IS_VALID(id))
#  else
#    ifdef PARAM_VAR_ID_INVALID
#      define PARAM_ID_VALID(id)    ((id) != PARAM_VAR_ID_INVALID)
#    elif defined(PARAM_VAR_ID_UNDEFINED)
#      define PARAM_ID_VALID(id)    ((id) != PARAM_VAR_ID_UNDEFINED)
#    else
#      define PARAM_ID_VALID(id)    ((id) != (paramVarId_t)-1)
#    endif
#  endif
#endif
// ----------------------------------------------------------

// ---------------- Konfiguration (per Param änderbar) ----------------
static volatile uint16_t cfgKickPct  = 15;     // %
static volatile uint16_t cfgHoldPct  = 5;      // %
static volatile uint16_t cfgKickMs   = 200;    // ms
static volatile uint8_t  cfgEnable   = 1;      // 1=aktiv
static volatile uint8_t  cfgForceRun = 0;      // 1=erzwinge Rotorlauf (Test)

/* pm.state-Wert, der "Charging" bedeutet
   0 Battery
   1 Charging
   2 Charged
   3 Low power
   4 Shutdown */
static volatile int      cfgPmChargingVal = 1;

// ---------------- Mock-Override mit TTL (per Param) ----------------
static volatile uint8_t  cfgMockEnable   = 0;     // 1: Mock aktiv
static volatile uint8_t  cfgMockCharging = 0;     // 1: "laden"-Ersatz
static volatile uint16_t cfgMockTtlMs    = 3000;  // Gültigkeit in ms
static TickType_t        mockTouchedTick = 0;
static int               prevMockCharging = -1;

// ---------------- Laufzeit-/Log-Status ----------------
typedef enum { QI_IDLE=0, QI_RUNNING } QiState;
static volatile uint8_t  lgState      = QI_IDLE;
static volatile uint8_t  lgCharging   = 0;
static volatile uint32_t lgPmStateRaw = 0;

// -------------- IDs für motorPowerSet & pm.state --------------
static paramVarId_t idMpEnable, idM1, idM2, idM3, idM4;
static logVarId_t   idPmState = (logVarId_t)-1;

// ----------------- Hilfsfunktionen -----------------
static inline uint16_t pctToRaw(uint16_t pct) {
  return (uint16_t)((UINT16_MAX / 100U) * pct);
}
static inline void setMotorRawAll(uint16_t raw) {
  paramSetInt(idM1, (int32_t)raw);
  paramSetInt(idM2, (int32_t)raw);
  paramSetInt(idM3, (int32_t)raw);
  paramSetInt(idM4, (int32_t)raw);
}
static inline void motorsStopAll(void) { setMotorRawAll(0); }

static bool detectCharging(void) {
  // --- Mock mit TTL vorschalten ---
  if (cfgMockEnable) {
    if ((int)cfgMockCharging != prevMockCharging) {
      prevMockCharging = (int)cfgMockCharging;
      mockTouchedTick  = xTaskGetTickCount();
    }
    const TickType_t now = xTaskGetTickCount();
    const TickType_t ttl = M2T(cfgMockTtlMs);
    if (ttl > 0 && (now - mockTouchedTick) < ttl) {
      lgCharging = cfgMockCharging ? 1 : 0;
      return cfgMockCharging != 0;
    }
    // TTL abgelaufen → auf echten PM-Pfad zurückfallen
  }

#ifdef PM_H_EXISTS
  // Primärweg, falls pm.h vorhanden: echte Ladeerkennung
  bool ch = pmIsCharging();
  lgCharging = ch ? 1 : 0;
  return ch;
#else
  // Fallback über Log-Variable pm.state
  if (LOG_ID_VALID(idPmState)) {
    uint32_t s = logGetUint(idPmState);
    lgPmStateRaw = s;
    bool ch = ((int)s == cfgPmChargingVal);
    lgCharging = ch ? 1 : 0;
    return ch;
  }
  lgCharging = 0;
  return false;
#endif
}

// ---------------- Param/Log-Gruppen ----------------
PARAM_GROUP_START(custom_qi)
PARAM_ADD(PARAM_UINT8,  enable,          &cfgEnable)
PARAM_ADD(PARAM_UINT8,  forceRun,        &cfgForceRun)
PARAM_ADD(PARAM_UINT16, kickPct,         &cfgKickPct)
PARAM_ADD(PARAM_UINT16, holdPct,         &cfgHoldPct)
PARAM_ADD(PARAM_UINT16, kickMs,          &cfgKickMs)
PARAM_ADD(PARAM_INT32,  pmChargingValue, &cfgPmChargingVal)
// Mock-Steuerung
PARAM_ADD(PARAM_UINT8,  mockEnable,      &cfgMockEnable)
PARAM_ADD(PARAM_UINT8,  mockCharging,    &cfgMockCharging)
PARAM_ADD(PARAM_UINT16, mockTtlMs,       &cfgMockTtlMs)
PARAM_GROUP_STOP(custom_qi)

LOG_GROUP_START(custom_qi)
LOG_ADD(LOG_UINT8,  state,     &lgState)
LOG_ADD(LOG_UINT8,  charging,  &lgCharging)
LOG_ADD(LOG_UINT32, pmState,   &lgPmStateRaw)
LOG_GROUP_STOP(custom_qi)

// --------------- Worker-Task ----------------------
static void customQiTask(void *arg) {
  (void)arg;
  QiState st = QI_IDLE;
  lgState = st;

  DEBUG_PRINT("[CUSTOM_QI] task started\n");

  for (;;) {
    vTaskDelay(M2T(20));

    if (!cfgEnable) {
      if (st != QI_IDLE) {
        motorsStopAll(); paramSetInt(idMpEnable, 0); st = QI_IDLE; lgState = st;
        DEBUG_PRINT("[CUSTOM_QI] disabled -> OFF\n");
      }
      continue;
    }

    const bool chg = detectCharging();
    const bool shouldRun = (cfgForceRun != 0) || chg;

    switch (st) {
      case QI_IDLE:
        if (shouldRun) {
          paramSetInt(idMpEnable, 1);                         // Bypass an
          setMotorRawAll(pctToRaw(cfgKickPct));               // Kick
          vTaskDelay(M2T(cfgKickMs));
          setMotorRawAll(pctToRaw(cfgHoldPct));               // Halte-PWM
          st = QI_RUNNING; lgState = st;
          DEBUG_PRINT("[CUSTOM_QI] -> RUN (chg=%d, force=%d)\n", chg, cfgForceRun);
        }
        break;

      case QI_RUNNING:
        if (!shouldRun) {
          motorsStopAll();
          paramSetInt(idMpEnable, 0);                         // Bypass aus
          st = QI_IDLE; lgState = st;
          DEBUG_PRINT("[CUSTOM_QI] -> IDLE\n");
        } else {
          // Halte-PWM regelmäßig setzen (robust ggü. Überschreiben)
          setMotorRawAll(pctToRaw(cfgHoldPct));
        }
        break;
    }
  }
}
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

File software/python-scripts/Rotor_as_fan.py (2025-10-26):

#!/usr/bin/env python3
# -*- coding: utf-8 -*-

import time
import logging
import csv
import uuid
from pathlib import Path
from datetime import datetime

import cflib.crtp
from cflib.crazyflie import Crazyflie
from cflib.crazyflie.syncCrazyflie import SyncCrazyflie
from cflib.crazyflie.log import LogConfig
from cflib.utils import uri_helper

# ------------------------------------------------------------
# Verbindung
# ------------------------------------------------------------
URI = uri_helper.uri_from_env(default='radio://0/80/2M/E7E7E7E7E5')

# ------------------------------------------------------------
# Motor-Setup (Direkt-PWM)
# ------------------------------------------------------------
PWM_PERCENT = 0.04                 # ≈ 5-10 %
PWM_MAX = 65535
PWM_VAL = max(0, min(PWM_MAX, int(round(PWM_PERCENT * PWM_MAX))))  # ≈ 3277
vbat = None

def set_all_motors(cf, val: int):
    cf.param.set_value('motorPowerSet.m1', str(val))
    cf.param.set_value('motorPowerSet.m2', str(val))
    cf.param.set_value('motorPowerSet.m3', str(val))
    cf.param.set_value('motorPowerSet.m4', str(val))

# ------------------------------------------------------------
# Logging-Konfiguration
# ------------------------------------------------------------
LOG_PERIOD_MS = 200  # Abtastrate der Telemetrie
LOG_DIR = Path("logs")
LOG_DIR.mkdir(parents=True, exist_ok=True)

RUN_ID = datetime.now().strftime("%Y%m%d-%H%M%S") + "-" + uuid.uuid4().hex[:6]
CSV_PATH = LOG_DIR / f"cf_powerlog_{RUN_ID}.csv"
CSV_HEADER = ["t_host_s", "baro.temp_C", "pm.batteryLevel_pct",
              "pm.chargeCurrent_mA", "pm.state", "pm.vbat_V"]

csv_file = None
csv_writer = None
t0 = None

def _fmt(val, ndigits=3):
    try:
        return f"{float(val):.{ndigits}f}"
    except Exception:
        return "nan"

def init_csv():
    global csv_file, csv_writer
    csv_file = CSV_PATH.open("w", newline="", encoding="utf-8")
    csv_writer = csv.writer(csv_file)
    csv_writer.writerow(CSV_HEADER)

def close_csv():
    global csv_file
    if csv_file:
        csv_file.flush()
        csv_file.close()
        csv_file = None

def on_log_data(timestamp, data, logconf):
    """Callback je Stichprobe: Konsole + CSV."""
    if csv_writer is None:
        return
    t = (time.time() - t0) if t0 is not None else 0.0
    global vbat, state

    batt = data.get("pm.batteryLevel")
    temp = data.get("baro.temp")
    ichg = data.get("pm.chargeCurrent")
    state = data.get("pm.state")
    vbat = data.get("pm.vbat")

    # Konsole
    print(f"[{t:7.2f}s] T={_fmt(temp,2)} °C | Vbat={_fmt(vbat,3)} V | "
          f"Batt={_fmt(batt,1)} % | Ichg={_fmt(ichg,1)} mA | pm.state={int(state) if state is not None else 'nan'}")

    # CSV (Werte in definierten Einheiten)
    csv_writer.writerow([
        f"{t:.3f}",
        _fmt(temp,3),
        _fmt(batt,3),
        _fmt(ichg,3),
        int(state) if state is not None else "",
        _fmt(vbat,3),
    ])

def on_log_error(logconf, msg):
    print(f"[LOG][ERROR] {msg}")

def safe_stop(cf, retries: int = 5, delay_s: float = 0.05):
    """
    Robuste Abschaltung für motorPowerSet:
    - Mehrfaches Setzen aller Motoren auf 0
    - Mehrfaches Deaktivieren von enable
    - Kurze Delays zwischen den Writes, damit ACKs sicher durchlaufen
    """
    for _ in range(retries):
        try:
            cf.param.set_value('motorPowerSet.m1', '0')
            time.sleep(delay_s)
            cf.param.set_value('motorPowerSet.m2', '0')
            time.sleep(delay_s)
            cf.param.set_value('motorPowerSet.m3', '0')
            time.sleep(delay_s)
            cf.param.set_value('motorPowerSet.m4', '0')
            time.sleep(delay_s)
            cf.param.set_value('motorPowerSet.enable', '0')
            time.sleep(delay_s)
        except Exception:
            # Nächster Versuch
            pass
    # Zusätzlich
    try:
        cf.commander.send_stop_setpoint()
    except Exception:
        pass
    # Kurze Wartezeit, damit alle Übertragungen abgeschlossen sind
    time.sleep(0.3)


# ------------------------------------------------------------
# Hauptprogramm
# ------------------------------------------------------------
if __name__ == "__main__":
    logging.basicConfig(level=logging.INFO)
    cflib.crtp.init_drivers()

    init_csv()
    print(f"[INFO] CSV-Logging nach: {CSV_PATH.resolve()}  (Periode: {LOG_PERIOD_MS} ms)")

    cf = Crazyflie(rw_cache='./cache')
    lg = None  # Referenz auf LogConfig für sauberes Stoppen

    with SyncCrazyflie(URI, cf=cf) as scf:
        # 1) Arm
        scf.cf.platform.send_arming_request(True)  # benötigt aktuelle Firmware
        time.sleep(1)

        try:
            # --- Telemetrie-Logging starten (asynchron, nicht blockierend) ---
            lg = LogConfig(name='PowerLog', period_in_ms=LOG_PERIOD_MS)
            lg.add_variable('baro.temp', 'float')
            lg.add_variable('pm.batteryLevel', 'float')
            lg.add_variable('pm.chargeCurrent', 'float')
            lg.add_variable('pm.state', 'uint8_t')
            lg.add_variable('pm.vbat', 'float')

            lg.data_received_cb.add_callback(on_log_data)
            lg.error_cb.add_callback(on_log_error)
            scf.cf.log.add_config(lg)

            t0 = time.time()
            lg.start()

            # 2) Direkt-PWM aktivieren
            scf.cf.param.set_value('motorPowerSet.enable', '1')  # 1 = PWM direkt an Motoren
            time.sleep(0.05)

            #Kickstart: einmal kurz auf 20% setzen, damit die Motoren sicher starten
            set_all_motors(scf.cf, int(0.2 * PWM_MAX))
            time.sleep(0.15)

            # 3) Alle Motoren auf ~5 % setzen
            set_all_motors(scf.cf, PWM_VAL)
            print(f"[INFO] Motors at ~{PWM_PERCENT*100:.1f}% PWM ({PWM_VAL}/{PWM_MAX})")

            # Testdauer: währenddessen läuft das Logging im Hintergrund
            while (vbat < 4.2) if vbat is not None else True:
                time.sleep(0.2)

        finally:
            # 4) Sicher abschalten (zuerst Motoren!)
            safe_stop(scf.cf, retries=6, delay_s=0.06)
            try:
                scf.cf.platform.send_arming_request(False)
            except Exception:
                pass

            # Logging stoppen & Datei schließen
            try:
                if lg is not None:
                    lg.stop()
            except Exception:
                pass
            close_csv()
            print("[INFO] Motors stopped and disarmed.")
            print(f"[INFO] Log-Datei geschrieben: {CSV_PATH.resolve()}")

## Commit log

2025-10-13 Add repo structure and kicad project
2025-10-13 Add repo structure
    [Boden.3mf, Deckel.3mf, TrichterV2.3mf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]
2025-10-17 Update step file reference in KiCad project
2025-10-17 Add fabrication files for pcb
    [crazyflie2-exp-custom-qi-deck-v4-B_Cu.gbl, crazyflie2-exp-custom-qi-deck-v4-B_Mask.gbs, crazyflie2-exp-custom-qi-deck-v4-B_Silkscreen.gbo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]
2025-10-17 Update README to include detailed project overview and assembly instructions for Custom-Qi-Deck
2025-10-18 Update README with improved image descriptions for Custom-Qi-Deck, adding webp animation for landing
2025-10-18 Add README and assembly files for Crazyflie-CAD project
    [6x15 motor mockup.SLDPRT, 7mm motor mount.SLDPRT, 7mm motor mount_Default_sldprt.STL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]
2025-10-26 Add Rotor_as_fan.py for motor control and telemetry logging
